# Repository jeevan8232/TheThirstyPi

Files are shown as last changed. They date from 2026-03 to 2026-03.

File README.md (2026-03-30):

# TheThirstyPi
Worry-free watering for the modern plant parent. It actively reads your soil moisture levels and waters your plants on demand, so you don't have to. Book that weekend getaway or extended vacation with total peace of mind—your garden is in good hands.

# Hand-Wiring the Electronics

Since we are keeping this accessible, there is no custom PCB required—everything is hand-wired directly to the microcontroller!

Hand-wiring a project like this is incredibly rewarding. Take your time, trim your wires to length so they fit nicely inside the shell, and double-check your connections as you go.

Below is the complete wiring guide based on the Raspberry Pi Pico (RP2040) pinout used for this project.

⚠️ Quick warning: Take it from me, never try to power a motor directly from your Pico’s pins. Motors are power-hungry and noisy, and they will absolutely fry your microcontroller. We are going to use the L293D Motor Driver as a heavy-duty bouncer to keep the power separate.

The Brain (Logic): Connect the L293D's logic power (VCC1 or 5V) to the Pico's VBUS pin. Connect the control pins: ENA to Pico GP10, IN1 (or 1A) to GP8, and IN2 (or 1B) to GP9.

The Muscle (Power): Connect the L293D's motor power (VCC2 or VMOTOR) directly to the positive wire of your 6V Battery Pack. Connect your water pump to the OUT1 and OUT2 (or 1Y and 2Y) pins.
The Golden Rule: You must connect the Pico's GND, the Battery Pack's GND, and the L293D's GND all together. If they don't share a common ground, your signals won't make sense to the chip.

Step 2: Giving It Senses

Next, we need to wire up the environmental sensors so the Pico actually knows what's going on in the dirt.

DHT11 (Temp/Hum): Connect VCC to Pico 3V3, GND to GND, and the Data pin to Pico GP14.
Soil Moisture Sensor: Connect VCC to Pico 3V3, GND to GND, and the Analog Output (A0) to Pico GP27 (ADC1).

(Optional) System Voltage: If you want to track battery voltage, I set up a quick voltage sensor module into Pico GP28 (ADC2).

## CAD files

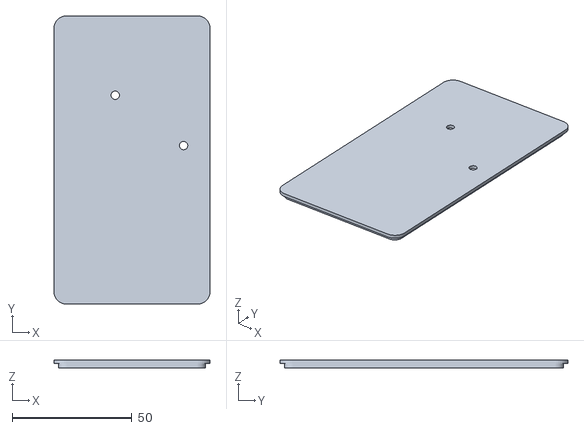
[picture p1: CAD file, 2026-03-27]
stl/COVER.stl
65.0 x 120.0 x 3.40

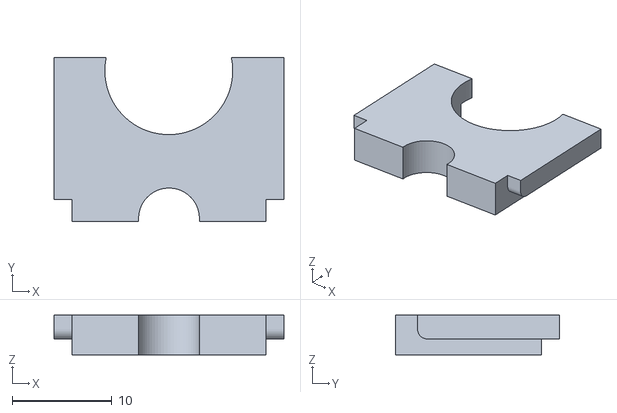
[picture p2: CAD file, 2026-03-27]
stl/SOIL MOISTURE SENSOR PROBE CASE.stl
23.1 x 16.5 x 4.00

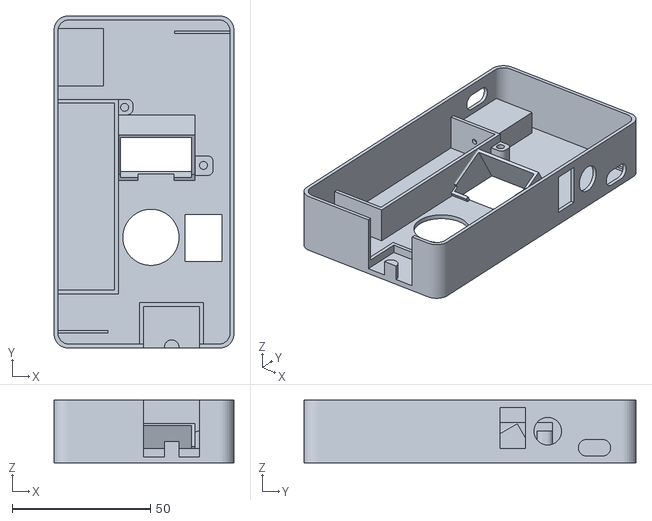
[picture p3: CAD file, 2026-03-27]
stl/BASE.stl
65.0 x 120.0 x 22.6

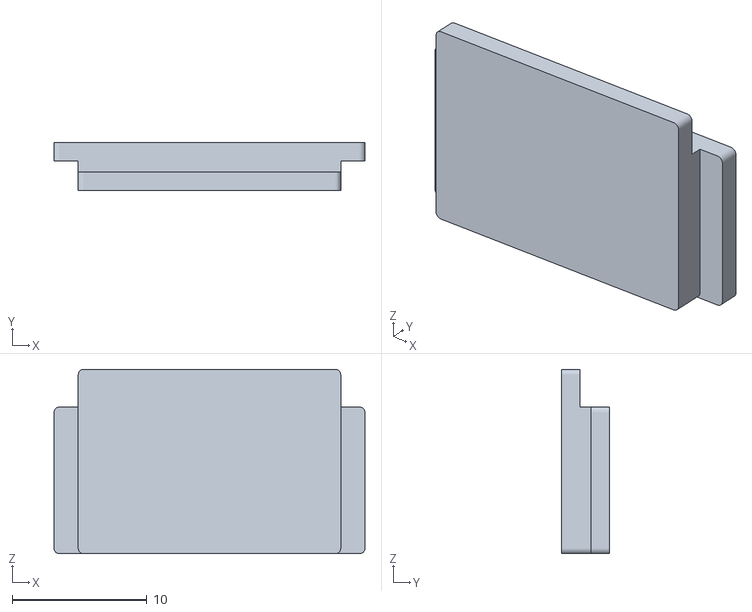
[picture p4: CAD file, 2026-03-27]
stl/SOIL PROBE COVER FILLER.stl
23.1 x 3.60 x 13.7

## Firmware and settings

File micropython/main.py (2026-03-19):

import network
import socket
import time
import json
import os
import ntptime
from machine import Pin, ADC
import dht

# ==========================================
# 1. CONFIGURATION
# ==========================================
WIFI_SSID = "<WIFI-SSID>"
WIFI_PASSWORD = "<WIFI-PASSWORD>"

AUTO_WATER_THRESHOLD = 30.0
SOIL_DRY = 65535
SOIL_WET = 20000 
PUMP_RUN_DURATION = 10

LOG_FILE = "datalog.csv"
MAX_FILE_SIZE = 1000000  
NORMAL_LOG_INTERVAL = 900  
ACTIVE_LOG_INTERVAL = 1    
TIMEZONE_OFFSET = 19800    

# ==========================================
# 2. HARDWARE SETUP
# ==========================================
dht_sensor = dht.DHT11(Pin(14))
adc_voltage = ADC(Pin(28))
adc_soil = ADC(Pin(27))

pump_ena = Pin(10, Pin.OUT, value=0) 
pump_1a  = Pin(8, Pin.OUT, value=0)  
pump_1b  = Pin(9, Pin.OUT, value=0)  

last_valid_temp = 0
last_valid_hum = 0
last_valid_rf = 0
last_dht_read_time = 0

# ==========================================
# 3. CORE FUNCTIONS & GLOBALS
# ==========================================
def control_pump(turn_on):
    if turn_on:
        pump_1a.value(1)
        pump_1b.value(0)
        pump_ena.value(1)
    else:
        pump_ena.value(0)
        pump_1a.value(0)
        pump_1b.value(0)

def calc_heat_index(t, h):
    if t < 20: return t
    hi = -8.78469475556 + 1.61139411*t + 2.33854883889*h - 0.14611605*t*h - \
         0.012308094*(t**2) - 0.01642482778*(h**2) + 0.002211732*(t**2)*h + \
         0.00072546*t*(h**2) - 0.000003582*(t**2)*(h**2)
    return round(hi, 2)

def get_readings():
    global last_valid_temp, last_valid_hum, last_valid_rf, last_dht_read_time
    current_time = time.time()
    
    if (current_time - last_dht_read_time) >= 2.5:
        try:
            dht_sensor.measure()
            last_valid_temp = dht_sensor.temperature()
            last_valid_hum = dht_sensor.humidity()
            last_valid_rf = calc_heat_index(last_valid_temp, last_valid_hum)
        except Exception:
            pass 
        last_dht_read_time = current_time
    
    raw_soil = adc_soil.read_u16()
    moisture = max(0, min(100, ((SOIL_DRY - raw_soil) / (SOIL_DRY - SOIL_WET)) * 100))
    volts = round((adc_voltage.read_u16() * (3.3/65535)) * 4.712, 2)
    
    return {
        "temp": last_valid_temp, "hum": last_valid_hum, "real_feel": last_valid_rf, 
        "soil": round(moisture, 1), "volts": volts, "pump": bool(pump_ena.value())
    }

def log_to_csv(data):
    file_exists = False
    try:
        file_size = os.stat(LOG_FILE)[6]
        file_exists = True
    except OSError:
        file_size = 0

    mode = 'w' if file_size > MAX_FILE_SIZE else 'a'
    try:
        with open(LOG_FILE, mode) as f:
            if mode == 'w' or not file_exists:
                f.write("Timestamp,Temp(C),RealFeel(C),Humidity(%),Soil(%),Volts(V),PumpOn,AutoMode,IgnoreMoist\n")
            
            t = time.localtime(time.time() + TIMEZONE_OFFSET)
            timestamp = f"{t[0]}-{t[1]:02d}-{t[2]:02d} {t[3]:02d}:{t[4]:02d}:{t[5]:02d}"
            log_line = f"{timestamp},{data['temp']},{data['real_feel']},{data['hum']},{data['soil']},{data['volts']},{data['pump']},{data['auto_mode']},{data['ignore_moisture']}\n"
            
            f.write(log_line)
            log_type = "[1s ACTIVE]" if data['pump'] else "[15m ROUTINE]"
            print(f"DEBUG LOG {log_type}: {log_line.strip()}")
    except Exception as e:
        print("Logging Error:", e)

# HTML Helper Function
def make_opt(val, text, current_val):
    sel = "selected" if str(val) == str(current_val) else ""
    return f'<option value="{val}" {sel}>{text}</option>'

# ==========================================
# 4. NETWORK & TIME SETUP
# ==========================================
wlan = network.WLAN(network.STA_IF)
wlan.active(True)
wlan.connect(WIFI_SSID, WIFI_PASSWORD)
print("Connecting to Wi-Fi...")
while not wlan.isconnected(): 
    time.sleep(1)
print("Connected! IP:", wlan.ifconfig()[0])

try:
    print("Syncing time via NTP...")
    ntptime.settime()
except Exception as e:
    print("NTP Sync Failed:", e)

s = socket.socket(socket.AF_INET, socket.SOCK_STREAM)
s.setsockopt(socket.SOL_SOCKET, socket.SO_REUSEADDR, 1)
s.bind(('', 80))
s.listen(5)
s.setblocking(False)

# ==========================================
# 5. MAIN EXECUTION & STATE VARIABLES
# ==========================================
last_water_time = 0
last_log_time = 0
pump_stop_time = 0

# --- NEW SETTINGS VARIABLES ---
auto_mode_enabled = True  
water_interval = 86400    # Default: 24 Hours (in seconds)
ignore_moisture = False   # Default: Smart Mode (Check soil first)

print("\n=== SYSTEM ACTIVE ===")
print("Press Ctrl+C to safely exit and turn off the pump.")

try:
    while True:
        current_time = time.time()
        data = get_readings()
        data["auto_mode"] = auto_mode_enabled 
        data["ignore_moisture"] = ignore_moisture
        data["interval"] = water_interval

        # --- NON-BLOCKING PUMP SHUTOFF ---
        if data['pump'] and current_time >= pump_stop_time:
            control_pump(False)
            data['pump'] = False
            print("\n>>> PUMP STOPPED (Timer Finished)")
            last_water_time = current_time 

        # --- DYNAMIC LOGGING LOGIC ---
        current_log_interval = ACTIVE_LOG_INTERVAL if data['pump'] else NORMAL_LOG_INTERVAL
        if (current_time - last_log_time) >= current_log_interval:
            log_to_csv(data)
            last_log_time = current_time

        # --- SMART SCHEDULE & AUTO-IRRIGATE TRIGGER ---
        time_since_last = current_time - last_water_time
        interval_met = time_since_last >= water_interval

        if auto_mode_enabled and not data['pump'] and interval_met:
            if ignore_moisture:
                # Timer Mode: Ignore the soil sensor entirely
                print("\n>>> TIMER MET: AUTO WATERING TRIGGERED (Cactus Mode)")
                control_pump(True)
                data['pump'] = True
                pump_stop_time = current_time + PUMP_RUN_DURATION
            else:
                # Smart Mode: Interval met, but check if soil is actually dry
                if data['soil'] < AUTO_WATER_THRESHOLD:
                    print("\n>>> SOIL DRY & INTERVAL MET: AUTO WATERING TRIGGERED")
                    control_pump(True)
                    data['pump'] = True
                    pump_stop_time = current_time + PUMP_RUN_DURATION

        # --- WEB SERVER LOGIC ---
        try:
            conn, addr = s.accept()
            conn.settimeout(1.0) 
            
            try:
                request = str(conn.recv(1024))
                
                # Manual Water ON
                if '/water/on' in request:
                    control_pump(True)
                    data['pump'] = True
                    pump_stop_time = time.time() + PUMP_RUN_DURATION
                    last_water_time = time.time() 
                    conn.send('HTTP/1.1 303 See Other\r\nLocation: /\r\n\r\n')
                
                # Manual Water OFF (Emergency Stop)
                elif '/water/off' in request:
                    control_pump(False)
                    data['pump'] = False
                    pump_stop_time = 0 
                    last_water_time = time.time() 
                    conn.send('HTTP/1.1 303 See Other\r\nLocation: /\r\n\r\n')
                
                # Toggle Master Auto-Mode
                elif '/auto/toggle' in request:
                    auto_mode_enabled = not auto_mode_enabled
                    last_water_time = time.time()
                    conn.send('HTTP/1.1 303 See Other\r\nLocation: /\r\n\r\n')
                    
                # Save Configuration Settings (From the HTML Form)
                elif '/config?' in request:
                    try:
                        # Parse URL parameters manually (MicroPython doesn't have urllib)
                        params = request.split('/config?')[1].split(' ')[0]
                        for param in params.split('&'):
                            key, val = param.split('=')
                            if key == 'interval':
                                water_interval = int(val)
                            elif key == 'ignore':
                                ignore_moisture = (val == '1')
                        print(f"\n>>> SETTINGS SAVED: Interval={water_interval}s, IgnoreMoist={ignore_moisture}")
                    except Exception as e:
                        print("Parse error on config:", e)
                    last_water_time = time.time() # Reset clock when settings change
                    conn.send('HTTP/1.1 303 See Other\r\nLocation: /\r\n\r\n')
                    
                elif '/api/readings' in request:
                    conn.send('HTTP/1.1 200 OK\r\nContent-Type: application/json\r\n\r\n')
                    conn.send(json.dumps(data).encode('utf-8'))
                    
                elif '/log' in request: 
                    try:
                        with open(LOG_FILE, 'r') as f:
                            csv_data = f.read()
                        conn.send('HTTP/1.1 200 OK\r\nContent-Type: text/csv\r\nContent-Disposition: attachment; filename="datalog.csv"\r\n\r\n')
                        conn.send(csv_data)
                    except OSError:
                        conn.send('HTTP/1.1 404 Not Found\r\n\r\nNo log file yet.')
                        
                # Web Dashboard
                else:
                    pump_status = "RUNNING 🟢" if data["pump"] else "OFF 🔴"
                    auto_status = "ACTIVE 🟢" if auto_mode_enabled else "PAUSED 🔴"
                    mode_text = "Timer Mode (Ignore Soil)" if ignore_moisture else "Smart Mode (Check Soil)"
                    
                    toggle_btn_color = "#e67e22" if auto_mode_enabled else "#27ae60"
                    toggle_btn_text = "⏸️ PAUSE AUTO-WATER" if auto_mode_enabled else "▶️ RESUME AUTO-WATER"

                    html = f"""<!DOCTYPE html><html><head><meta charset="utf-8"><title>Pico Garden</title><meta name="viewport" content="width=device-width, initial-scale=1">
                    <style>
                    body{{font-family:Arial;text-align:center;background:#eef2f3;padding:20px;}} 
                    .card{{max-width:350px;margin:0 auto;background:white;padding:25px;border-radius:12px;box-shadow:0 4px 10px rgba(0,0,0,0.1); box-sizing:border-box;}}
                    .btn{{display:block;color:white;padding:15px;text-decoration:none;border-radius:8px;margin-top:15px;font-weight:bold; cursor:pointer; border:none; width:100%; box-sizing:border-box;}}
                    .btn-group{{display:flex;gap:10px;margin-top:15px;}}
                    .btn-group .btn{{margin-top:0; flex:1;}}
                    .btn-water{{background:#3498db;}} .btn-water:active{{background:#2980b9;}}
                    .btn-stop{{background:#e74c3c;}} .btn-stop:active{{background:#c0392b;}}
                    .btn-save{{background:#8e44ad;}} .btn-save:active{{background:#732d91;}}
                    .btn-log{{background:#2c3e50;margin-top:25px;}}
                    .settings-box{{background:#f8f9fa; border:1px solid #ddd; padding:15px; border-radius:8px; margin-top:20px; text-align:left; box-sizing:border-box;}}
                    .settings-box label{{font-size:13px; font-weight:bold; color:#555; display:block; margin-bottom:5px;}}
                    select{{width:100%; padding:10px; margin-bottom:15px; border-radius:5px; border:1px solid #ccc; font-size:14px; box-sizing:border-box;}}
                    h1{{color:#2980b9;margin:0;font-size:3em;}}
                    </style></head><body>
                    <div class="card">
                    <h2 style="margin-bottom: 5px;">🪴 The Thirsty Pi</h2>
                    <p style="color:#7f8c8d; font-style:italic; font-size: 14px; margin-top:0; margin-bottom:20px; line-height: 1.4;">
                        Smartly water your thirsty plants. Enjoy your vacation with total peace of mind!
                    </p>
                    
                    <h1>{data['soil']}%</h1><p style="color:#7f8c8d; margin-top:5px;">Soil Moisture</p>
                    <p style="margin-bottom:5px;">🌡️ Temp: <b>{data['temp']}°C</b> &nbsp;|&nbsp; 💧 Hum: <b>{data['hum']}%</b></p>
                    <p style="margin-top:0; color:#7f8c8d; font-size:14px;">(Feels like {data['real_feel']}°C)</p>
                    <hr>
                    <p>Pump Status: <b>{pump_status}</b></p>
                    <p>Auto Master Switch: <b>{auto_status}</b></p>
                    <p style="color:#8e44ad; font-size:14px;">Current Logic: <b>{mode_text}</b></p>
                    
                    <div class="btn-group">
                        <a href="/water/on" class="btn btn-water">🌊 WATER</a>
                        <a href="/water/off" class="btn btn-stop">🛑 STOP</a>
                    </div>
                    <a href="/auto/toggle" class="btn" style="background:{toggle_btn_color};">{toggle_btn_text}</a>
                    
                    <div class="settings-box">
                        <form action="/config" method="GET">
                            <label>Watering Frequency (Interval)</label>
                            <select name="interval">
                                {make_opt(60, '1 Minute (Test Mode)', water_interval)}
                                {make_opt(3600, '1 Hour', water_interval)}
                                {make_opt(43200, '12 Hours', water_interval)}
                                {make_opt(86400, '24 Hours', water_interval)}
                                {make_opt(259200, '3 Days', water_interval)}
                                {make_opt(604800, '1 Week', water_interval)}
                            </select>
                            
                            <label>Sensor Mode</label>
                            <select name="ignore">
                                {make_opt(0, 'Smart Mode (Wait for Dry Soil)', 1 if ignore_moisture else 0)}
                                {make_opt(1, 'Timer Mode (Ignore Soil / For Cactus)', 1 if ignore_moisture else 0)}
                            </select>
                            <button type="submit" class="btn btn-save">💾 SAVE SCHEDULE</button>
                        </form>
                    </div>

                    <a href="/log" class="btn btn-log">📊 DOWNLOAD LOGS</a>
                    <p><small style="color:#bdc3c7;">Auto-refreshes 8s</small></p></div>
                    
                    <script>
                        let timer = setTimeout(function(){{location.reload();}}, 8000);
                        document.querySelectorAll('select').forEach(el => {{
                            el.addEventListener('focus', () => clearTimeout(timer));
                        }});
                    </script>
                    </body></html>"""
                    
                    conn.send('HTTP/1.1 200 OK\r\nConnection: close\r\nContent-Type: text/html; charset=utf-8\r\n\r\n')
                    conn.send(html.encode('utf-8'))
            
            except OSError:
                pass 
            finally:
                conn.close() 
                
        except OSError:
            pass 
        
        time.sleep(0.2) 

finally:
    print("\n[!] Program interrupted or stopped.")
    print("[!] Clearing all hardware pins...")
    control_pump(False)
    try:
        s.close()
    except:
        pass
    print("Cleanup complete. Safe to exit.")
